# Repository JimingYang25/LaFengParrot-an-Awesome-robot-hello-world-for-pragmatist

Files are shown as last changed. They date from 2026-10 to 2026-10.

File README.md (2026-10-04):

# LaFengParrot

LaFengParrot is a 3D-printable, Jetson-powered parrot table robot with a
MuJoCo model and a reinforcement-learning locomotion stack. The mechanical
design targets a Jetson Orin Nano Super 8 GB and commonly available parts.

This repository is an engineering starting point for developers and
researchers who want to design, train, evaluate, and deploy their own robot
policies. It provides a reproducible mechanical and simulation baseline rather
than a finished consumer product.

## Current status
屏幕录制 2026-10-05 033540

- MuJoCo model: 10 actuators and a floating base; stable passive standing.
- Controller: PPO residual policy around an alternating six-joint leg reference.
- Verified checkpoint: `h008`, evaluated with 8% training-harness strength.
- Fixed-seed result: 19/20 episodes (`126..145`), zero cross-foot
  contacts, and about 0.54 m mean forward travel per 20 s.
- Graduation target: harness `0.00` and 20/20 strict evaluation episodes.
- Contact safety: floor contact and foot-to-foot collision are classified
  separately; any cross-foot contact fails evaluation.
- Current limitation: seed `141` exposes an early startup balance failure at
  `h008`, so the checkpoint is a development baseline, not a deployable gait.

exploded

The harness provides only lateral and attitude stabilization. It applies no
forward force, so forward travel must come from the robot's gait.

## Repository layout

| Path | Contents |
| --- | --- |
| `CAD/` | Parametric Python CAD sources, assembly notes, drawings, STL and STEP exports |
| `robot_description/` | MJCF, URDF, USD, meshes, kinematics and verification tools |
| `rl/` | Gymnasium environments, PPO training, evaluation and policy viewers |
| `BOM.md` | Bill of materials and component notes |

Policy developers should begin with the
[policy development and tuning guide](docs/POLICY_DEVELOPMENT.md). It explains
the observation/action contract, safe curriculum workflow, tuning controls,
evaluation gates, and how to connect another RL implementation.

## Verified development environment

- Windows with WSL2 Ubuntu 24.04
- Python 3.12 in a Conda environment
- MuJoCo 3.14.0
- Gymnasium 1.3.0
- Stable-Baselines3 2.9.0
- PyTorch 2.14.0 with CUDA 13.0

The saved policy uses a 60-value normalized observation, separate two-layer
`256 x 256` actor and critic networks, and a 10-value action vector. Only the
six leg residuals currently affect the walking command; wings and neck remain
at their reference positions.

## Clone the repository

```bash
git clone https://github.com/JimingYang25/LaFengParrot__An-Awesome-starting-point-for-your-policy.git LaFengParrot
cd LaFengParrot
```

All commands below are run from the repository root.

## Install Python dependencies

Python 3.12 is recommended. Create and activate an isolated environment, then
install the tested dependencies:

```bash
python -m pip install -r requirements.txt
```

For CUDA training, install the PyTorch wheel matching the host's CUDA setup
before running the command above. The CUDA-local build version may include a
suffix such as `+cu130`.

## Validate the robot model

From WSL2:

```bash
python robot_description/make_mjcf.py
python robot_description/verify_mjcf.py
```

## Watch the current policy

```bash
python rl/watch_gait_policy.py --harness 0.08
```

`--harness 0.00` is an experimental unassisted preview. The current checkpoint
has not yet passed the graduation test at that setting.

## Evaluate the checkpoint

```bash
python rl/evaluate_gait_ppo.py --episodes 20 --harness 0.08 --device cpu
```

The repository retains `rl/runs/gait_ppo_v3_valid/gait_ppo_final.zip` and its
`vecnormalize.pkl`. Intermediate checkpoints, TensorBoard logs, Python caches,
MuJoCo crash logs, and large generated SVG drawings are intentionally ignored.

## Next milestone

1. Improve startup robustness from 19/20 to 20/20 at harness `0.08`.
2. Gradually anneal the harness to zero without losing the collision gate.
3. Expand reset and push randomization, then repeat fixed-seed evaluation.
4. Validate actuator limits and add a hardware emergency-stop layer before
   transferring any learned policy to the physical robot.

## Collaboration and contact

Bug reports, reproducible experiments, and focused improvements are welcome
through GitHub issues and pull requests. For deeper collaboration involving
robot hardware, reinforcement learning, deployment, or research, contact
[2132720978@qq.com](mailto:2132720978@qq.com).

## License

Copyright 2026 Jiming ([JimingYang25](https://github.com/JimingYang25)).

This project—including its source code, robot descriptions, CAD files, and
documentation—is licensed under the [Apache License 2.0](LICENSE), unless a
file states otherwise.

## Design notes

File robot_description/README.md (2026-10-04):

# LaFengParrot — robot_description (REV-B)

Floating-base biped/quadriped-style parrot robot description for RL, generated **from the real
CadQuery CAD** (REV-B) into three mutually consistent formats:

| Format | File | Primary use |
|---|---|---|
| MJCF | `mjcf/lafengparrot.xml` | **PPO training asset (MuJoCo)** — primary |
| URDF | `urdf/lafengparrot.urdf` | PyBullet / ROS / general tooling |
| USD | `usd/lafengparrot.usd` | Isaac Sim / Isaac Lab (PhysX baked) |

All three are generated from **one frozen parameter source** (`kinematics.json`) + the real CAD
solids (meshes + inertials), so kinematic anchors, limits, inertials and contacts agree by
construction. A cross-format checker (`verify_cross.py`) re-asserts this on every run.

---

## 1. Kinematic tree (floating base, 10 actuated joints)

```
trunk (base_link, free joint — floating)
├── hip_roll_L (axis X)  ─ hip_pitch_L (Y) ─ knee_L (Y) ─ shin_L + foot
├── hip_roll_R (axis X)  ─ hip_pitch_R (Y) ─ knee_R (Y) ─ shin_R + foot
├── wing_flap_L (axis Y) ─ wing arm (fixed)
├── wing_flap_R (axis Y) ─ wing arm (fixed)
└── neck_yaw (axis Z) ─ neck_pitch (Y) ─ head
```

- **Servo mapping:** legs = Feetech **ST-3215-C018** (6×, effort 2.72 N·m); wings/neck = Feetech
  **SC-0043-C001** (4×, effort 0.22 N·m). All 10 on one FT-SCS bus in the real robot.
- **Zero pose = standing** (all joints at 0; soles level at global z = −138 mm).
- **Joint limits (deg; [EST] microduck-like):**

| joint | axis | origin (mm, trunk frame) | range |
|---|---|---|---|
| hip_roll L/R | X | (0, ±27, 0) | ±22° |
| hip_pitch L/R | Y | (0, ±27, −42) | ±90° |
| knee L/R | Y | (0, ±27, −84) | 0…150° |
| wing_flap L/R | Y | (0, ±62, 60) | ±45° |
| neck_yaw | Z | (0, 0, 133) | ±90° |
| neck_pitch | Y | (0, 0, 185) | ±45° |

## 2. Joint indexing — READ BEFORE WRITING RL CODE

MuJoCo assigns **qpos/qvel order by tree DFS** (leg-major): `hip_roll_L, hip_pitch_L, knee_L,
hip_roll_R, hip_pitch_R, knee_R, wing_flap_L, wing_flap_R, neck_yaw, neck_pitch` — this is the
correct, stable model order and must NOT be "re-ordered" by restructuring the tree.

The **actuator (ctrl) order is canonical** (kinematics.json order) because actuators bind to
joints by name.

→ Use `joint_name_index_map.json` to map names ↔ indices. **Index observations/actions BY NAME,
never by hard-coded position.**

| index type | layout |
|---|---|
| qpos (17) | 0–2 freejoint trans, 3–6 freejoint quat, 7–16 hinges (DFS order) |
| qvel (16) | 0–5 freejoint (3 trans + 3 rot), 6–15 hinges (DFS order) |
| ctrl (10) | canonical: hip_roll_L, hip_roll_R, hip_pitch_L, hip_pitch_R, knee_L, knee_R, wing_flap_L, wing_flap_R, neck_yaw, neck_pitch |

## 3. How to load

**MJCF (MuJoCo, PPO asset):**
```python
import mujoco
model = mujoco.MjModel.from_xml_path("mjcf/lafengparrot.xml")
data = mujoco.MjData(model)   # nq=17, nv=16, nu=10
```
- Position actuators (joint-target interface, 50 Hz): `ctrl` **in radians**, `ctrlrange` radians.
- Contacts: only the ten fixed sole facets (five per foot) touch the floor; the 32 mm flat
  centres provide standing stability and the raised toe/heel facets permit rollover. These are
  not wheels; visual/hull geoms remain `contype=0`.
  ground friction 1.0; sole friction (0.9, 0.005, 0.0001).
- `imu_trunk` site on the trunk at (0, 0, 0.05).
- Init helper: to start standing with the physical CAD sole on the ground, set the free base z
  so the trunk sits ≈ +0.138 m (the model itself has trunk pos = 0).

**URDF:**
```python
from urdfpy import URDF
r = URDF.load("urdf/lafengparrot.urdf")
```
- PyBullet: `p.loadURDF(..., useFixedBase=False)` — trunk becomes the 6-DOF floating base
  (no world joint needed). **PyBullet could not be installed on this machine (Python 3.14 has
  no wheel; source build fails on missing Python.h) — loading was verified with urdfpy instead
  (11 links / 10 joints, zero-pose FK reproduces all link frame origins with 0 error).**
- ROS: a world→base_link floating joint is added by the loader.

**USD (Isaac):**
```python
from pxr import Usd
stage = Usd.Stage.Open("usd/lafengparrot.usd")
```
- Physics **is baked**: ArticulationRootAPI ×1, RigidBodyAPI ×11, MassAPI ×11 (incl. diagonal
  inertia + principal axes), PhysicsRevoluteJoint ×10, DriveAPI ×10 (kp=40, kv=4, maxForce =
  servo effort), CollisionAPI ×13 (11 hulls + 2 sole cubes), visual UsdGeomMesh ×11.
- metersPerUnit = 1, up = Z. Load directly into Isaac Sim/Lab; joints are resolved by name.
- Drive stiffness/damping is a single set (legs and wings/neck not differentiated) — split per
  joint if needed.

## 4. Meshes & inertials (from the real CAD)

- `meshes/visual/<link>.stl` — tessellated real CadQuery solids (linear deflection 0.4 mm),
  already in each link's frame, **millimeters** (consumers scale: MuJoCo mesh scale="0.001").
- `meshes/collision/<link>_col.stl` — convex hulls for the same bodies.
- MJCF sole contact: five thin box facets per foot follow the 40×44 mm CAD rocker profile;
  the flat centre underside is local z=−54 mm and both ends rise to z=−52 mm.
- `inertials.json` — per-link mass (g), CoM (mm, link frame), inertia (kg·m², about CoM, link axes);
  includes the 105 g fastener/bearing/cable lump [EST] distributed by mass fraction.

**Mass & CoM reconciliation (matches REV-B CAD):**
total **1483.8 g** (target ≈ 1.485 kg) · whole-robot CoM height above floor **162.57 mm**
(target 162.5 mm).

## 5. Verification summary (2026-09-27)

| Check | Result |
|---|---|
| MJCF loads in mujoco | nq=17, nv=16, nu=10; 10/10 ranges; 400-step neutral sim stable, zero warnings, ncon=16; physical sole underside z = −0.1380 |
| Rocker crouch sweep | 0/10/15/20/25/30° knee targets all stable for 8 s; continuous contact; maximum trunk tilt 7.4° |
| URDF parses | urdfpy 11 links / 10 joints; axes+limits 10/10; zero-pose FK error 0.00e+00 m (PyBullet unavailable on Py3.14 — stated) |
| USD opens via pxr | ArticulationRootAPI 1, rigid bodies 11, revolute joints 10, drives 10, collision 13; axes+limits 10/10 |
| Cross-format | `verify_cross.py`: content 10/10 per format; URDF order canonical; MJCF actuator order canonical (qpos DFS documented); USD 10 names present (hierarchy-embedded) → **ALL THREE CONSISTENT** |

## 6. Generation pipeline (re-runnable)

```
CAD (poses.py, registry, dims) + dimensions.json
        └─ generate_meshes.py   → meshes/visual/*.stl, meshes/collision/*_col.stl, inertials.json
kinematics.json (single source)
        ├─ make_mjcf.py  (+ verify_mjcf.py)   → mjcf/lafengparrot.xml
        ├─ make_urdf.py  (+ verify_urdf.py)   → urdf/lafengparrot.urdf
        └─ make_usd.py   (+ verify_usd.py)    → usd/lafengparrot.usd
verify_cross.py   → cross-format consistency
make_name_map.py  → joint_name_index_map.json (from the actual MuJoCo model)
```

## 7. [EST] / limitations (honest list)

- **PyBullet load test skipped**: no Python 3.14 wheel; source build fails (missing Python.h).
  URDF correctness rests on urdfpy parse + FK.
- **Joint damping 0.5, frictionloss 0.05, kp=40, kv=4, armature 0.01 (legs) / 0.002 (wings·neck):
  [EST]** — tunable for PPO.
- **105 g lump** (fasteners/bearings/cables) and its placement: [EST].
- USD drives: single kp/kv set for all 10 joints; split per joint if needed.
- Joint limits are microduck-like estimates; verify against the physical servos (ST-3215 300°/s,
  SC-0043 similar) on first assembly.
- REV-B inherited values are authoritative here: hip rail 54 mm (±27), neck pitch local z 52 /
  global 185, carrier board-top z=72, soles z = −138, 40×44 soles, CoM 162.5 mm.

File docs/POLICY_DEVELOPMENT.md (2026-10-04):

# Policy development and tuning

This guide is for developers who want to fine-tune the included PPO policy,
change the locomotion task, or connect a different reinforcement-learning
algorithm to LaFengParrot.

The repository is a starting point, not a graduated walking controller. The
included checkpoint is usable with a training harness strength of `0.08`, but
it has not passed the assisted 20/20 gate or the unassisted (`0.00`)
graduation gate. Foot-to-floor and foot-to-foot contacts are classified
separately and covered by regression tests.

## 1. Reproduce the baseline first

Install the dependencies from the repository root:

```bash
python -m pip install -r requirements.txt
```

Validate the generated MuJoCo model:

```bash
python robot_description/make_mjcf.py
python robot_description/verify_mjcf.py
```

Evaluate and view the shipped checkpoint at its verified harness level:

```bash
python -m unittest -v tests.test_gait_contacts
python rl/evaluate_gait_ppo.py --episodes 20 --harness 0.08 --device cpu
python rl/watch_gait_policy.py --harness 0.08 --device cpu
```

Expected baseline for seeds `126..145`: 19/20 episodes pass, no episode has a
cross-foot contact, and seed `141` ends in an early startup balance failure.
Do not begin tuning until the model verifier, contact tests, and this baseline
are reproducible.

## 2. Understand the policy contract

The gait task is implemented in
[`rl/lafengparrot_gait_env.py`](../rl/lafengparrot_gait_env.py). It is a
residual controller: a phase-driven reference trajectory supplies the nominal
leg targets, and the policy adds bounded corrections every 20 ms.

```text
joint target = reference trajectory + filtered policy action * residual scale
```

### Observation

The observation contains 60 normalized values:

- 41 standing-state values: base height and orientation, ten joint positions,
  sixteen velocities, and the previous ten filtered actions.
- Two gait-clock values: sine and cosine of phase.
- Four foot position values: X/Z for the left and right feet.
- Four foot velocity values: X/Z for the left and right feet.
- Two measured contact flags.
- Two contact-point slip speeds.
- Four gait-event one-hot values.
- One current harness-strength value.

Global X/Y position is intentionally excluded so the policy does not depend on
where the robot happens to be in the world.

### Action

The action space is a ten-value `Box(-1, 1)`. The current gait controller uses
policy corrections on six leg joints:

| Action | Joint | Maximum residual correction |
| ---: | --- | ---: |
| 0 | `hip_roll_L` | +/-8 degrees |
| 1 | `hip_roll_R` | +/-8 degrees |
| 2 | `hip_pitch_L` | +/-18 degrees |
| 3 | `hip_pitch_R` | +/-18 degrees |
| 4 | `knee_L` | +/-20 degrees |
| 5 | `knee_R` | +/-20 degrees |
| 6-9 | Wings and neck | Disabled for gait (`0` scale) |

Actions are low-pass filtered as `0.8 * previous + 0.2 * new`. Changing the
action order, observation order, or observation size makes the shipped model
and `vecnormalize.pkl` incompatible unless their weights/statistics are
migrated deliberately.

### Harness

The training harness applies lateral stabilization and corrective body torque.
It never applies forward force. `1.0` is maximum training assistance and `0.0`
is fully unassisted. Treat harness reduction as a curriculum, not a reward
setting to change abruptly.

## 3. Use the environment with another algorithm

`LaFengParrotGaitEnv` follows the Gymnasium API, so it can be connected to
another RL library or a custom control loop:

```python
import numpy as np

from rl.lafengparrot_gait_env import LaFengParrotGaitEnv

env = LaFengParrotGaitEnv(
    target_speed=0.025,
    harness_strength=0.50,
    reset_noise_scale=0.25,
)

obs, info = env.reset(seed=0)
for _ in range(1000):
    action = np.zeros(env.action_space.shape, dtype=np.float32)
    obs, reward, terminated, truncated, info = env.step(action)
    if terminated or truncated:
        break

env.close()
```

For learned policies, normalize observations and preserve the normalization
statistics alongside every checkpoint. During evaluation, freeze observation
statistics and disable reward normalization.

## 4. Fine-tune the shipped PPO baseline

Create an experiment branch before training because the trainer writes its
final model back to `rl/runs/gait_ppo_v3_valid/`:

```bash
git switch -c policy/my-experiment
```

First stabilize any reward or environment change without reducing assistance:

```bash
python rl/train_gait_ppo.py \
  --resume \
  --quiet \
  --steps 200000 \
  --envs 8 \
  --reset-noise-scale 0.25 \
  --learning-rate 0.00005 \
  --start-harness 0.08 \
  --end-harness 0.08 \
  --device cuda
```

Re-evaluate at `0.08`. Only after reaching 20/20 with zero cross-foot contacts
should assistance be reduced. Use a slow stage rather than a jump:

```bash
python rl/train_gait_ppo.py \
  --resume \
  --quiet \
  --steps 1200000 \
  --envs 16 \
  --start-harness 0.08 \
  --end-harness 0.07 \
  --decay-fraction 1.0 \
  --device cuda
```

Then run:

```bash
python rl/evaluate_gait_ppo.py --episodes 10 --harness 0.07 --device cpu
python rl/analyze_gait_policy.py --harness 0.07
python rl/analyze_gait_actions.py 0.07
```

If the pass rate regresses, restore the last passing checkpoint rather than
continuing from a degraded policy. Keep the model ZIP and its matching
`vecnormalize.pkl` together.

The non-resume path in `train_gait_ppo.py` transfers weights and normalization
from `rl/runs/stand_ppo_rocker32/`. Those older standing artifacts are not
included in this repository. Public users should therefore fine-tune the
included gait checkpoint with `--resume`, or replace the standing-transfer
calls with an explicit initialization strategy in their own trainer.

## 5. Main tuning controls

Change one group at a time and record the commit, seed, harness schedule, and
evaluation results.

| Control | Location | Effect and risk |
| --- | --- | --- |
| Target speed | `--speed` | Changes the commanded forward-speed target. Increase gradually. |
| Harness schedule | `--start-harness`, `--end-harness`, `--decay-fraction` | Controls curriculum difficulty. Large jumps commonly destroy a passing gait. |
| Reference motion | `REFERENCE_KNOTS` | Changes lift, swing, touchdown, and double-support timing. Verify contact order after editing. |
| Gait frequency | `gait_frequency` | Changes cadence. Faster is not automatically more stable or faster forward. |
| Leg authority | `residual_scale` | Larger values permit recovery but also increase saturation and violent motion. |
| Initial-state difficulty | `--reset-noise-scale` | Improves robustness when raised gradually. |
| Resume learning rate | `--learning-rate` | Lower values reduce policy drift during narrow robustness refinements. |
| Reward terms | `step()` reward expression | Can change the learned behavior completely; validate physical metrics, not reward alone. |
| PPO optimization | `PPO(...)` in `train_gait_ppo.py` | Tune learning rate, rollout length, batch size, entropy, and network size conservatively. |

Monitor PPO training with:

```bash
tensorboard --logdir rl/runs/gait_ppo_v3_valid/tensorboard --port 6006
```

MuJoCo simulation remains primarily CPU-bound. CUDA accelerates the neural
network updates, while parallel environments increase simulation throughput.
More environments are useful only while the CPU can keep them supplied.

## 6. Evaluate physical behavior, not only reward

The provided evaluator marks an episode as passed only when:

- It does not terminate early.
- It completes at least four gait cycles.
- Every completed cycle is classified as a successful forward cycle.
- Trunk displacement is at least 0.08 m.
- No left/right sole collision occurs, even momentarily.

The gait audit additionally requires:

- Mean same-foot footprint advance above 5 mm.
- Worst integrated contact skid no greater than 8 mm.
- Every recorded touchdown lead above 3 mm.

A candidate graduates only after 20/20 deterministic episodes at harness
`0.00`, followed by visual inspection and action-saturation review. A policy
that stands on one leg, marches in place, slides its feet, or depends on the
harness has not graduated.

## 7. Contact-safety implementation

`_contacts_now()` reports a stance contact only for a sole-versus-floor pair.
Left/right sole contacts are counted independently, penalized immediately,
and terminate an episode when they persist for three control steps. The
evaluator is stricter: even one cross-foot contact makes the episode fail. A
lateral-separation term discourages leg crossing before collision.

The regression tests include a captured crossed-foot configuration lifted
above the floor. This verifies that self-collision is detected without being
misreported as ground contact or contact slip:

```bash
python -m unittest -v tests.test_gait_contacts
```

Keep physical collision enabled. The real robot cannot pass one foot through
the other, and disabling collision would invalidate the gait result.

## 8. Contribution workflow

Keep each change focused and make its result reproducible:

```bash
git switch -c policy/short-description
git add <changed-files>
git commit -m "Describe the policy change"
git push -u origin policy/short-description
gh pr create --base main
```

Include the training seed, steps, harness schedule, pass rate, mean distance,
gait-audit output, and a short video when opening a pull request. For deeper
hardware, RL, deployment, or research collaboration, contact
[2132720978@qq.com](mailto:2132720978@qq.com).

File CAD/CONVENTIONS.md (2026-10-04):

# LaFengParrot CAD — Conventions & Interfaces (FROZEN 2026-09-27)

This file is the contract every CAD module builds against. Do not deviate silently; if a convention is wrong, change this file and notify the other agents.

## 1. Paths (all Windows, absolute)

* CAD root: the repository-relative `CAD/` directory

* `dims\dimensions.json` + `dims\dimensions.md` — the ONLY source of truth for hardware dimensions (produced by the dimension-research agent; every number has `verified: true/false` and a `source` URL).

* `source\lib\` — hardware solid builders (servos, carrier, battery, power, fasteners, bearings). Pure functions: no frame/trunk design here.

* `source\frame\` — robot structural parts (trunk, legs, wings, neck, head, mounts, panels).

* `source\assembly\` — poses, full-assembly build, clash checks, drawings/export scripts.

* `exports\step\`, `exports\stl\`, `drawings\` — outputs.

* `ASSEMBLY.md` — part tree ↔ BOM mapping, dimension table, fastener list, cable routing, joint axes/zero poses.

## 2. Units & coordinate frame

* Units: **millimeters** everywhere. Mass in grams (metadata only).

* Global frame (right-handed): **+X forward** (parrot faces +X), **+Y left** (parrot's left), **+Z up**.

* Origin `(0,0,0)`: point on the sagittal plane midway between the two **hip\_roll output axes**, at the height of those axes (this is the "hip plane"). Legs hang below (−Z), trunk above (+Z), neck above trunk.

* Every part module builds in **its own local frame** (sensible local origin, documented in META\["origin\_note"]); the assembly module applies poses to place it.

## 3. Module API (every part file)

Each builder file in `source\lib\` and `source\frame\` exposes exactly:

```
META = {

&#x20; "part\_id": "trunk\_shell",            # unique, snake\_case, matches STL/STEP filenames

&#x20; "name": "Trunk shell (PETG)",

&#x20; "bom\_line": "§2 #9 / §6 #15",        # maps to BOM line(s); "n/a" for hardware

&#x20; "qty": 1,

&#x20; "mass\_g": 230.0,                     # datasheet/estimate

&#x20; "material": "PETG | aluminum | PCB | LiPo | steel",

&#x20; "source\_url": "...",                 # datasheet/listing; "n/a" for designed parts

&#x20; "origin\_note": "local frame: ...",

&#x20; "print\_note": "orientation, supports, split hint (if printed)",

}

def build(cfg=None):

&#x20;   """Return a cq.Solid (or cq.Workplane, callers normalize) of the part

&#x20;   in its local frame. cfg: optional dict for parametric overrides."""

&#x20;   ...
```

Registry: `source\registry.py` provides `all_parts() -> dict[part_id, module]` by importing every module in lib + frame and collecting `META` + `build`. Assembly iterates the registry.

## 4. Hardware dimensions — read ONLY from `dims\dimensions.json`

Frame parts that mount hardware (servo pockets, carrier standoffs, battery tray, hole patterns) MUST take their numbers from `dimensions.json`, never hardcode a dimension that exists in the JSON. The JSON schema (keys per part):

```
{

&#x20; "st3215\_c018": {

&#x20;    "body": {"l": 45.2, "w": 24.7, "h": 35.0},

&#x20;    "mount": {"holes": \[\[x1,y1],\[x2,y2],...], "diameter": 2.2, "screw": "M2"},

&#x20;    "shaft": {"spline": "25T", "outer\_d": 6.0, "length": 6.0, "axis\_dir": "body\_long"},

&#x20;    "horn": {"span": 40.0, "arm\_count": 4, "screw\_holes": "M2"},

&#x20;    "connector": {"type": "JST-PH 3pin", "location": "face\_opposite\_shaft"},

&#x20;    "mass\_g": 55.0,

&#x20;    "source": "\<url>", "verified": true

&#x20; },

&#x20; "sc0043\_c001": {...},

&#x20; "orin\_carrier": {"envelope": \[103,90.5,34.8], "board": \[100,79,1.6],

&#x20;    "mount\_holes": \[\[x,y],...], "mount\_screw": "M2.5",

&#x20;    "connectors": {"barrel": \[x,y], "40pin": \[x,y], "csi1": \[x,y], "csi2": \[x,y],

&#x20;                   "microsd": \[x,y], "usb": \[x,y], "fan\_exhaust": \[x,y]},

&#x20;    "module\_center": \[x,y], "source": "\<url>", "verified": false},

&#x20; "lipo\_3s\_2200": {"size": \[l,w,h], "mass\_g": 185, "connector": "XT60", "balance": "JST-XH", ...},

&#x20; "bec\_5v3a": {...}, "xt60\_switch": {...}, "fuse\_holder": {...},

&#x20; "imuc\_icm42688p": {...}, "bearing\_mr63": {"d":3,"D":6,"B":2.5}, "bearing\_mr84": {"d":4,"D":8,"B":2},

&#x20; "fastener\_m2": {"head\_d":3.8,"head\_h":2.0,"thread":2.0,"clear":2.2},

&#x20; "fastener\_m25": {"head\_d":4.5,"head\_h":2.5,"thread":2.5,"clear":2.7},

&#x20; "fastener\_m3": {"head\_d":5.5,"head\_h":3.0,"thread":3.0,"clear":3.2}

}
```

If a number is missing from the JSON, the frame part uses `[EST]` value from `dimensions.md` and marks it in `META["origin_note"]`. Never invent silently.

## 5. Clearances & print rules (PETG FDM)

* Moving-pair radial fit: shaft-in-bearing / servo-horn-on-shaft → nominal + **0.1–0.2 mm** on the bore, printed in PETG.

* Non-moving press/slip: screw boss bore = thread + 0.1 (self-tap) or clearance per §4 fastener table.

* Face-to-face mating clearance: **0.3–0.5 mm** on mating bosses/tabs.

* Wall thickness: structural walls **≥ 2.0 mm**, servo pockets **≥ 1.6 mm**, cosmetic shell **1.6 mm**.

* Screw bosses: OD = head\_d + 2× wall (min 6.0 mm for M2/M2.5, 6.8 for M3 at 2 mm wall), boss height ≥ 2× screw engagement.

* Print splits: the trunk shell is split (long axis or clamshell) so each printed piece fits ≤ 220×220 mm bed — mark `print_note` with the split; final split decision waits for the user's printer bed (flag, don't block).

* Corner radii ≥ 1 mm on printed parts (avoid stress risers); print orientation note in `print_note` (surfaces that must be dimensionally clean face away from supports).

## 6. Kinematic anchors & joint axes (MUST match the final ASSEMBLY.md and later MuJoCo model)

* **Legs (3 DOF/leg, mirroring microduck scaled to parrot):**

  * hip\_roll: axis ∥ **X** (frontal-plane abduction). Left/right hip\_roll axes separated **54 mm (±27 mm from sagittal, realized)**. Servo: ST-3215-C018, output shaft along X.

  * **CHANGE RECORD (2026-09-27, assembly clash check):** hip half-spacing widened from 34 mm to 52 mm total (planned) and realized at **54 mm (±27)** after the REV-B rebuild. Root cause: the ST-3215-C018 body (45.2×24.7×35, 55 g) makes the hip\_mount housing 50.6 mm wide in Y and the thigh link 38.4 mm wide; at ±17 mm the L/R housings, thigh beams and hip\_roll servo bodies overlap across the sagittal plane (measured 0.6–9.6 cm³ intersections). 54 mm total gives ≥1.5 mm per-side clearance on the widest part. Torque: hip\_roll lever arm r ≈ **33 mm** (half-spacing 27 + 6 mm roll margin) → required @2× = 0.961 N·m at M=1.485 kg vs C018 stall ≈ 2.72 N·m @11.1 V → **PASS with 2.83× margin** (still \~3.0× at the 1.38 kg frame+hardware mass). **MuJoCo kinematics must use 54 mm spacing** (recorded in ASSEMBLY.md).

  * hip\_pitch: axis ∥ **Y** (sagittal swing), located **42 mm** below the hip\_roll axis (thigh length between hip\_pitch output and knee axis).

  * knee\_pitch: axis ∥ **Y**, located **42 mm** below hip\_pitch (thigh link), shin runs **50 mm** from knee axis to ankle/foot (shin link).

  * Foot: small ground-contact pad at shin end, \~10 mm above floor in zero pose; keep CoM low (battery lowest, carrier above).

* **Wings (2 DOF):** one flap DOF each. Axis ∥ **Y** (wings spread sideways ±) — wing servo (SC-0043) mounted at the shoulders, output axis lateral, wing arm extending in the ±Y direction with a printed airfoil-ish flat panel.

* **Neck (2 DOF):** neck\_yaw axis ∥ **Z**, then neck\_pitch axis ∥ **Y**, both stacked above the trunk top, lifting the head \~60–80 mm above the trunk; head shell on top with beak + crest.

* **Zero pose (standing):** trunk vertical; all leg joint angles = 0 (legs straight down); wings level (±Y); neck straight up (yaw=0, pitch=0). The crouched gait (hip\_pitch 26°/knee \~0°) is a *policy* offset, not the CAD zero — record both in ASSEMBLY.md so MuJoCo inherits exact axes.

* **REV B — STABILITY REVISION (2026-09-27, user-directed):**

  * **Foot (in shin\_link, 2026-09-28 rocker update):** fixed compound-rocker sole **40 (X, heel→toe) × 44 (Y, lateral) × 4 mm maximum**, centered on the shin axis. The centre 32 mm is flat at local z = −54; two 2 mm facets per end rise through −53.4 to −52 at heel and toe. It is one printed solid with the shin—**not a wheel and not an extra assembly**. Leg drop remains 138 mm. Lateral inner gap between L/R soles = 10 mm (inner edges at y=±5 with track ±27).

  * **Neck:** neck\_linkage pitch axis lowered **z=70 → z=52** (H\_n = 52 mm, −26%): base+yaw block unchanged (0–25.4), yoke shortened; both SC-0043 servos keep full travel. Head crest falls accordingly (global pitch axis 203 → **185**). Head-pitched-down travel check: head shell front must clear the trunk roof (≥3 mm) at −45° pitch.

  * **Carrier mount (low CoG):** carrier board-top **z=101 → z=72** (realized; feet bottom ≈ 65.4, standoffs ≈ **33 mm \[EST]** from the trunk floor 33; cooler exhaust ≈ 100 with the roof vent at \~131.5 → \~28 mm plenum above; airflow is plenum-style, not direct). Battery tray seated on the trunk floor (base at z=33), battery stays y=−23 low.

  * **Cable stubs:** both servo modules' cosmetic 150 mm cable cylinders shortened to **15 mm** exit stubs (envelope becomes structural: x\[−56,+70], y\[−189,+189], z\[−138,\~250]).

  * **CoM target:** whole-robot CoM height ≤ \~180 mm using real frame mass (456 g PETG at 1.27) + hardware masses (\~1.36 kg total); support-polygon lateral half-base 49 mm (stance outer edge), forward half-base 20 mm; tipping angle = atan(half-base/CoM\_z). These revised dims are what the later MuJoCo model must inherit.

## 7. Assembly & outputs

* `source\assembly\poses.py`: one `def poses() -> dict[part_id, cq.Location]` for the standing pose and `def exploded() -> dict[part_id, cq.Location]` (offsets along ±X/±Y/±Z, ≥ 30 mm apart per direction).

* Full assembly STEP: `exports\step\LaFengParrot_full.STEP`; per-part STEP + STL also exported (STL in local frame, `print_note` gives print orientation — do NOT rotate STLs).

* Drawings (deterministic, from CAD data — NO AI image generation): front (XY), side (YZ) orthographic with key dimensions; exploded isometric. PNG + SVG (+ PDF if convenient). Use matplotlib-based projection of the part solids (or OCP offscreen if working).

* Clash check: pairwise solid intersection volume (OCP `BRepAlgoAPI_Common`) over the standing pose, report any pair with volume > 0.01 mm³; also confirm service access (microSD slot, XT60, barrel jack, 40-pin) is not fully enclosed.

## 8. Reporting

Every agent returns: absolute paths of outputs, the dimension table it used (with verified/EST + URL), fit/clash results, and any dimension it could NOT verify (explicitly marked). Nothing fabricated; unverifiable → \[EST] + flagged.

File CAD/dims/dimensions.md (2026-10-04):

# LaFengParrot CAD — Hardware Mechanical Dimensions

Build variant: **all-Feetech** — legs 6× ST-3215-C018 (12 V, 30 kg·cm), wings/neck 4× SC-0043-C001.
Units: mm (mass g). Research date 2026-09-27.

**Legend:** ✅ verified = read from a datasheet / product page this session. ⚠ [EST] = estimated; see the register at the end for the basis.

---

## 1. Feetech ST-3215-C018 (leg servos, ×6)

Source: official datasheet PDF https://www.feetech.cn/Data/feetechrc/upload/file/20240507/6385067068652648096680943.pdf ; outline drawing https://www.feetechrc.com/en/525603.html

| Dimension | Value (mm) | Verified? | Source | Notes |
|---|---|---|---|---|
| Body L × W × H | 45.2 × 24.7 × 35.0 | ✅ | datasheet §6-1 | "45.2X24.7X35" |
| Mount holes (output face) | 4× at (6.5,2.5)/(27.2,2.5)/(6.5,22.2)/(27.2,22.2) | ⚠ [EST] | measured off drawing Fig.9 | drawing does not label hole coords; pocket dim = body box |
| Mount hole Ø / screw | Ø2.2 / M2 (PA2.0 self-tap) | ⚠ [EST] | drawing "B-PA2.0自攻螺丝" | 4 corner PA2.0 case screws at ~(1.7,1.1)/(43.5,1.1)/(1.7,23.6)/(43.5,23.6) are case fasteners |
| Output shaft spline | 25T | ✅ | datasheet §6-9 | "25T/OD5.9mm" |
| Output shaft O/D | 5.9 | ✅ | datasheet §6-9 | |
| Output shaft length | ~6.0 | ⚠ [EST] | horn section X-X | dual-shaft (双轴); rear plain bore ~Ø6 opposite face |
| Axis direction | normal to 45.2×24.7 face | ✅ | drawing | |
| Horn: flange O/D | 19.95 (~20) | ✅ | horn drawing | octagonal flange |
| Horn: hub bore | 25T / Ø5.9 | ✅ | horn drawing "25T(5.9铜齿)" | |
| Horn: arm / bracket screws | 4× M3 (on ~Ø14 BCD) + 4× Ø3.2 clearance (~Ø9 BCD) | ✅ | horn drawing "4-M3" / "Ø3.2" | |
| Horn retaining screw | M3×6 | ✅ | datasheet §6-13 "M3X6机牙螺丝" | |
| Horn thickness | flange 2.5 / hub 4.5 | ✅ | horn section X-X | |
| Connector | 5264-3P, 2.54 pitch, 3-pin (GND/Vcc/SIG), 15 cm cable | ✅ | datasheet §6-7 | on bottom face opposite shaft |
| Mass | 55 g (±1) | ✅ | datasheet §6-8 | |

---

## 2. Feetech SC-0043-C001 (wings/neck servos, ×4)

Source: product page https://www.feetech.cn/en/559569

| Dimension | Value (mm) | Verified? | Source | Notes |
|---|---|---|---|---|
| Body L × W × H | 20.3 × 8.5 × 19.39 | ✅ | product page "A:20.3 B:8.5 C:19.39" | |
| Mount holes | 2 ears, Ø~2.0, center spacing 20.3 | ⚠ [EST] | outline drawing | bottom view dims 27.35 outer / 23.6 body / 20.3 hole spacing |
| Mount screw | M2 | ⚠ [EST] | drawing "Φ2" ear holes | |
| Output shaft spline | 28T | ✅ | product page "28T/Φ3.9mm" | |
| Output shaft O/D | 3.9 | ✅ | product page | |
| Output shaft protrusion | 3.1 | ✅ | side view "3.1" | |
| Horn retaining screw | M1.7 | ✅ | drawing "28T-M1.7" | |
| Stock horn arm span | ~15 | ⚠ [EST] | typical 4.3 g servo horn | |
| Connector | 3-pin bus, 15 cm cable | ✅ | product page "Connector wire: 15cm" | exact JST family not published |
| Mass | 6.6 g (±0.5) | ✅ | product page | |

---

## 3. Jetson Orin Nano Super dev-kit reference carrier + stock cooler

Source: NVIDIA Carrier Board Spec SP-11324-001 https://developer.nvidia.com/downloads/assets/embedded/secure/jetson/orin_nano/docs/jetson_orin_nano_devkit_carrier_board_specification_sp.pdf (Fig 4-1, Fig 4-2)

Coordinate system: origin = top-left of the 100×79 PCB, +X right, +Y down (mm).

| Dimension | Value | Verified? | Source | Notes |
|---|---|---|---|---|
| Overall envelope (w/ cooler+feet) | 103.0 × 90.5 × 34.77 mm | ✅ | Fig 4-2 | 103±0.2 / 90.5±0.2 / 34.77±1.09 |
| PCB size | 100.0 × 79.0 mm | ✅ | Fig 4-1 | 100±0.13 / 79±0.13 |
| PCB thickness | 1.57 mm | ✅ | Fig 4-1 side view | 1.57±0.16 |
| Component height (top side) | 16.70 mm max | ✅ | Fig 4-1 side view | |
| Component height (bottom) | 4.30 mm max | ✅ | Fig 4-1 side view | |
| Mount holes | (4,4)/(96,4)/(4,56)/(96,56) | ⚠ [EST] | measured off Fig 4-1 raster | spec gives no coords; 4 corner plated holes |
| Mount screw | M2.5 | ⚠ [EST] | standard dev-kit standoff | |
| Feet / standoff height | ~5 mm | ⚠ [EST] | BOM §2 CAD note | |
| Connector: DC barrel (J16) | (10, 66) | ⚠ [EST] | Fig 4-1 | barrel 5.5 O/D, 2.5 pin, 9.5 mm long (verified §3.8) |
| Connector: 40-pin header (J12) | (35, 5) | ⚠ [EST] | Fig 4-1 | top edge |
| Connector: CSI #0 (J20) | (3, 21) | ⚠ [EST] | Fig 4-1 | left edge, upper flex connector |
| Connector: CSI #1 (J21) | (3, 40) | ⚠ [EST] | Fig 4-1 | left edge, lower flex connector |
| Connector: microSD slot | (68, 62) | ⚠ [EST] | Fig 4-1 | bottom edge |
| Connector: USB cluster (USB-C J5) | (25, 68) | ⚠ [EST] | Fig 4-1 | USB-A J6/J7 at ~(42,68)/(55,68) |
| Fan exhaust (blows upward off heatsink) | (50, 30) | ⚠ [EST] | Fig 4-2 fan center | |
| SoDIMM module center | (48, 28) | ⚠ [EST] | Fig 4-1 | module sits above long SoDIMM slot |
| Dev-kit assembly mass | 175 g | ✅ | §4 "Developer Kit Weighs 0.175kg" | |

---

## 4. 3S 11.1 V 2200 mAh LiPo (XT60)

Source: Zeee listing https://zeeebattery.com/products/zeee-3s-lipo-battery-2200mah-11-1v-120c-xt60 (cross-checked Gens Ace / HRB / Rhino)

| Dimension | Value | Verified? | Source | Notes |
|---|---|---|---|---|
| Pack L × W × H | 105 × 34.5 × 26 mm | ✅ | Zeee listing | brands vary 105×33–35×19–27; Gens Ace 105×34×23, Rhino 107×35×26.5 |
| Mass | 185 g | ✅ | Zeee listing | |
| Discharge connector | XT60 | ✅ | listing | |
| Balance lead | JST-XH 4-pin | ✅ | listings | exits same end as XT60 |

---

## 5. 5 V / 3 A BEC module

| Dimension | Value | Verified? | Source | Notes |
|---|---|---|---|---|
| Board L × W × H | 30 × 20 × 10 mm | ⚠ [EST] | generic | small 2-side buck PCB; exact size varies by brand |
| Wire length | ~100 mm leads | ⚠ [EST] | generic | |
| Mass | 15 g | ⚠ [EST] | BOM §7 | |

---

## 6. XT60 power switch + inline fuse holder

| Dimension | Value | Verified? | Source | Notes |
|---|---|---|---|---|
| XT60 housing | 17.5 × 21.5 × 14 mm | ⚠ [EST] | standard XT60 part | |
| Inline switch body | 50 × 25 × 20 mm | ⚠ [EST] | generic | XT60 leads + rocker toggle |
| Glass fuse | Ø5 × 20 mm | ✅ | standard 5×20 | |
| Fuse holder body | 30 × 15 × 10 mm | ⚠ [EST] | generic inline holder | |

---

## 7. ICM-42688-P IMU breakout

Source: chip datasheet https://product.tdk.com/system/files/dam/doc/product/sensor/mortion-inertial/imu/data_sheet/ds-000347-icm-42688-p-v1.6.pdf

| Dimension | Value | Verified? | Source | Notes |
|---|---|---|---|---|
| Chip package | 2.5 × 3.0 × 0.91 mm LGA | ✅ | TDK datasheet | the bare IC |
| Breakout PCB | 20 × 20 × 2 mm | ⚠ [EST] | generic GY breakout | 4× M2 holes at corners (2,2)/(18,2)/(2,18)/(18,18), Ø2.2 |
| Mass | 4 g | ⚠ [EST] | BOM §2 | |

---

## 8. Bearings

| Bearing | d (bore) | D (outer) | B (width) | Verified? | Source |
|---|---|---|---|---|---|
| MR63ZZ | 3.0 | 6.0 | 2.5 | ✅ | https://detail.1688.com/offer/570803238776.html |
| MR84 (open) | 4.0 | 8.0 | 2.0 | ✅ | https://www.ktbearing.com/product/deep-groove-ball-bearing/deep-groove-ball-bearing-mr-series/ |

Note: shielded **MR84ZZ** is 4×8×**3** mm; the open MR84 used in the joint pockets is 4×8×2.

---

## 9. Fasteners (DIN 912 / ISO 4762 socket head cap screws)

Source: https://engineeringhardware.com/guide/standard/din-912-socket-head-cap-screws/

| Size | Head Ø dk | Head height k | Thread | Clearance hole | Lengths in BOM | Verified? |
|---|---|---|---|---|---|---|
| M2 | 3.8 | 2.0 | 2.0 | 2.2 | M2×6 | ✅ |
| M2.5 | 4.5 | 2.5 | 2.5 | 2.7 | M2.5×8 | ✅ |
| M3 | 5.5 | 3.0 | 3.0 | 3.2 | M3×10 | ✅ |

---

## Unverifiable / [EST] register

Every number below could NOT be read directly from a datasheet this session and is an estimate. Frame parts consuming these MUST mark them in `META["origin_note"]`.

| # | Item | Estimated value | Basis / method |
|---|---|---|---|
| 1 | ST-3215-C018 mount-hole xy coords | (6.5,2.5)/(27.2,2.5)/(6.5,22.2)/(27.2,22.2) | pixel-measured off the Fig.9 outline raster; drawing labels only body box (45.2×24.7) and shaft. Verify against physical servo. |
| 2 | ST-3215-C018 shaft protrusion length | ~6.0 mm | inferred from horn/hub section (hub 4.5 + spline engagement); not explicitly dimensioned. |
| 3 | SC-0043-C001 mount hole spacing | 20.3 mm | from bottom-view dimension "20.3" on the outline drawing; ear hole Ø~2 inferred (drawing labels Φ2 near shaft). |
| 4 | SC-0043-C001 horn arm span | ~15 mm | typical 4.3 g micro-servo horn; not on drawing. |
| 5 | SC-0043-C001 connector JST family | "3-pin" only | product page says 15 cm wire but not the connector part number. |
| 6 | Orin carrier mount-hole xy | (4,4)/(96,4)/(4,56)/(96,56) | pixel-measured off Fig 4-1 raster; NVIDIA spec gives board outline but no hole coordinates. |
| 7 | Orin carrier all connector xy (barrel/40pin/csi1/csi2/microsd/usb/fan/module center) | per table above | pixel-estimated off Fig 4-1/4-2 raster. |
| 8 | Orin carrier feet height | ~5 mm | BOM §2 packing note; not in SP-11324. |
| 9 | Orin carrier mount screw size | M2.5 | standard dev-kit standoff; not explicitly stated. |
| 10 | BEC 5V3A board size / wires / mass | 30×20×10 mm, 100 mm leads, 15 g | generic small buck module; BOM lists it as a generic item. |
| 11 | XT60 housing size | 17.5×21.5×14 mm | standard XT60 (not re-verified from a datasheet this session). |
| 12 | XT60 switch body size | 50×25×20 mm | generic inline switch listing. |
| 13 | Fuse holder body size | 30×15×10 mm | generic 5×20 inline holder. |
| 14 | ICM-42688-P breakout PCB size / holes | 20×20×2 mm, 4×M2 corners | generic GY breakout; only the bare chip (2.5×3×0.91) is datasheet-verified. |

No values were fabricated: every servo dimension the frame needs (body box, mount holes, shaft, horn) is present, every carrier connector coordinate is present (flagged [EST] where estimated), and every row carries either a verified source URL or an explicit [EST] basis.

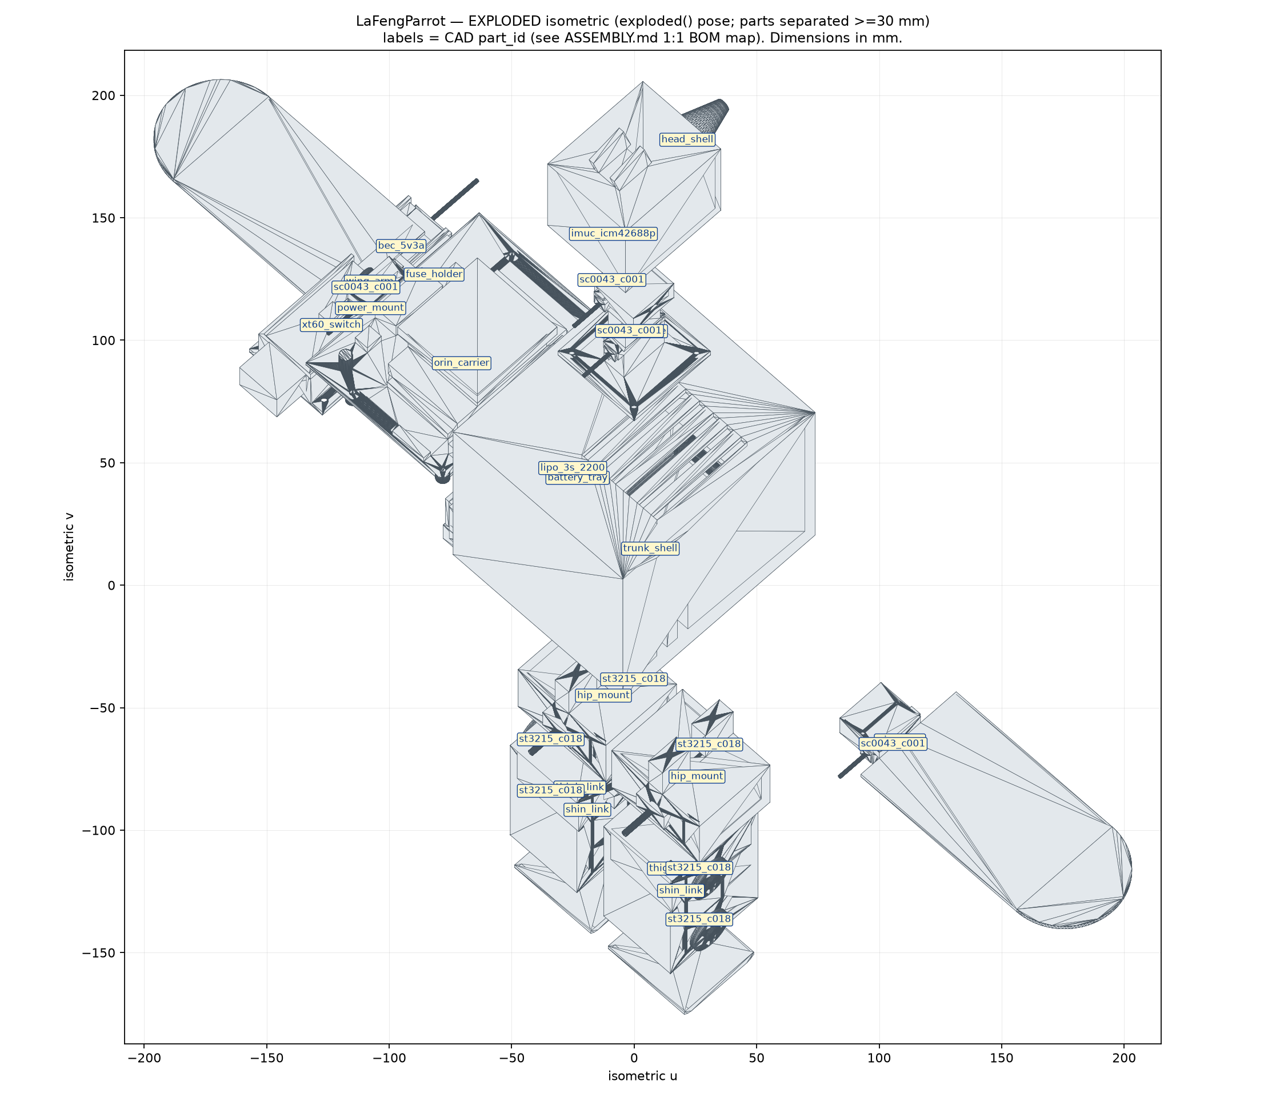
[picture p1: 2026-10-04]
CAD/drawings/exploded.png

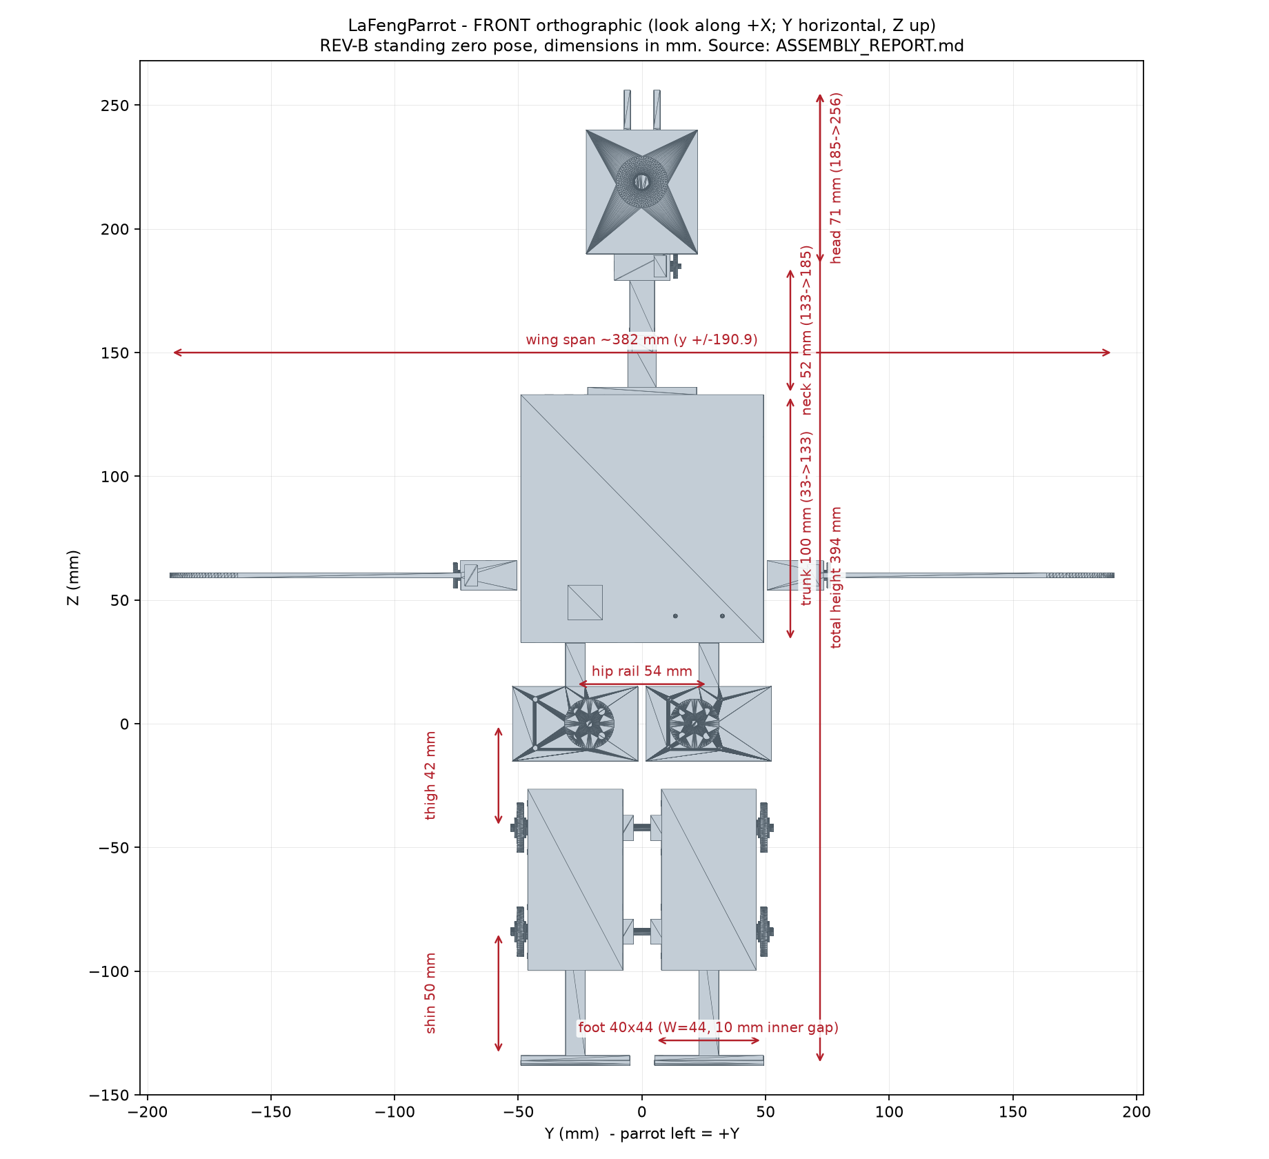
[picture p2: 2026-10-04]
CAD/drawings/front.png

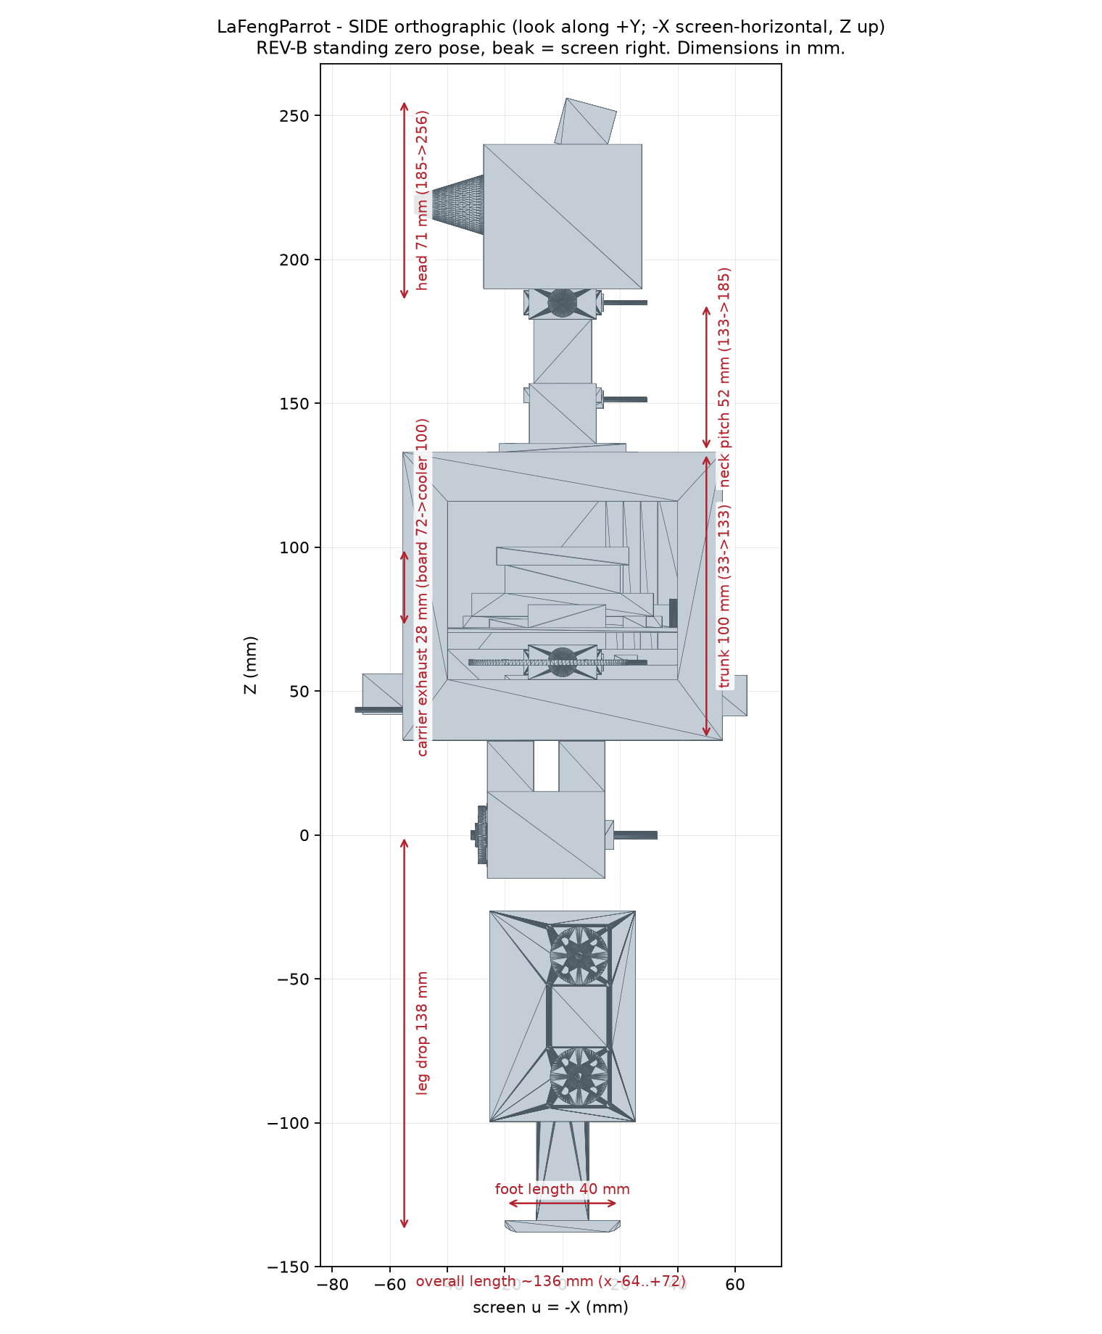
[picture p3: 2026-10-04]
CAD/drawings/side.png

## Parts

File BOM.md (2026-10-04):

# LaFengParrot — BOM & Engineering Baseline (Sep 2026, All-Domestic Edition)

**Project:** Parrot-shaped pet robot, ~25 cm class, analog of pollen-robotics/microduck.
**Compute (OWNED ✅, purchased 2026-09):** NVIDIA Jetson Orin Nano Super 8 GB **official developer kit** — module TW-T013-8GB mounted on the NVIDIA **reference carrier** with the **stock active cooler (heatsink+fan) pre-mounted**; JD [item 10149183026930](https://ic-item.jd.com/10149183026930.html). **The robot carries the reference carrier + stock cooler exactly as they ship** (cost ¥0, but their mass counts in §2); the A603 carrier / Waveshare cooler / NVMe are **NOT purchased**. Module: 69.6×45 mm, 260-pin SO-DIMM, 7/15/25 W, 67 INT8 TOPS.
**Behaviors (user-frozen v1):** bipedal WALK (microduck RL method), wing FLUTTER ×2, neck SHAKE/tilt. **NO flight.**
**Pricing snapshot:** 2026-09-27 (Sep 2026), CNY. **ALL materials purchasable inside mainland China** (Taobao/Tmall/JD/1688/domestic official flagship stores), domestic shipping only — no foreign-shipping options anywhere. Every value marked [ESTIMATE] is an inference, not a confirmed price; nothing was fabricated. FX ≈ 7.2 CNY/USD [ESTIMATE].

---

## 0. Scope — CORE vs OPTIONAL / DEFERRED

**CORE (v1, this BOM, 10 DOF, one servo bus):**
| Group | DOF | Servo |
|---|---|---|
| Legs ×2 — hip_roll + hip_pitch + knee_pitch (3 DOF/leg, BDX/OpenDuck-style) | 6 | Dynamixel XC330-M288-T |
| Wings ×2 — single flap DOF each (doubles as balance appendages during gait) | 2 | Dynamixel XL330-M288-T |
| Neck — yaw + pitch | 2 | Dynamixel XL330-M288-T |
| **Total core** | **10** | **6× XC330 + 4× XL330** |

**OPTIONAL (labeled, NOT core — v2+):**
- Legs → mirror microduck's *actual* 5 DOF/leg (add hip_yaw ±27°, ankle ±90°): **+4 servos ≈ +¥3,200, +46 g**. Microduck's real legs are 5 DOF (`hip_yaw, hip_roll, hip_pitch, knee, ankle` — 10 of its 15 servos); the extra yaw/ankle refine the waddle but the RL method (PPO in MuJoCo Warp, 50 Hz ONNX) transfers either way. [RL-README]
- Head/crest roll (+1), beak articulation, tail, camera, speaker/TTS, ToF, gamepad (teleop).

**DEFERRED (out of core, per scope):** everything above not in CORE or OPTIONAL.

---

## 1. Research corrections vs the working assumptions (read first)

1. **Microduck legs are 5 DOF, not 3** — `hip_yaw / hip_roll / hip_pitch / knee / ankle` per side, 10 servos; plus 4 head/neck servos + 1 beak servo = 15. There are **no wing or tail servos in microduck**. The beak is deliberately excluded from the RL action vector and daemon-driven. Its real geometry (from the shipping MuJoCo MJCF): trunk at z=0.12 m standing, hip half-spacing ≈34 mm, thigh ≈42 mm, shin ≈50 mm, crouch pose = hip_pitch 26° / ankle 26° / knee ~0°, robot 250×140 mm, **780 g**. [MJCF][CONST][ROBOTD-DESIGN]
2. **XL330/XC330-M288-T share a hard 6.0 V absolute max** — there is no 7.4 V operation for these SKUs (the 9–12 V row in the eManual belongs to the XC330-T288, a different model). A 2S pack (8.4 V charged) overvolts them. Microduck *does* run XL330s straight off the 2S NP-F550 rail (6.5–8.2 V) and clears the overvoltage-shutdown bit (shutdown=52) — a proven-but-out-of-spec hack. **This build does not copy that**: servos run from a regulated 6.0 V rail. [ROBOTD-DESIGN][XL330][XC330]
3. **Dynamixel bus connector is 3-pin JST-EH** (Robot Cable-X3P), not 4-pin. X4P is RS-485 Dynamixels only. [XL330][CN-CHANNEL]
4. **No surveyed Orin carrier accepts 2S (7.4 V) directly** — every board's input regulator cuts out at 9 V minimum. The LiPo that fits all 9–20 V carriers is **3S 11.1 V (9.9–12.6 V)**. [CARRIER]
5. **The open sibling Open Duck Mini independently converged on XC330 legs** — repo README: *"I switched to using `xc330-M288-T` servomotors instead of `xl330-M288-T` for the legs. They are more expensive, but way more powerful."* This is external validation of the torque analysis in §3. [ODM]
6. **Domestic-channel price correction (Sep 2026):** the earlier "MicroDuck crunch ¥950–1800" figure was overstated. Verified domestic prices today: **XL330-M288-T ¥95 (智能佳机器人, authorized distributor, in stock, verified 2026-09-02) / ¥238 (WowRobo, 48 h ship, 100+ orders) / ¥120–188 (1688)**; **XC330-M288-T ≈ ¥800 (multiple Taobao "韩国原装正品" listings), ¥700–900 band**. ROBOTIS has no Tmall/JD flagship — its China office (china@robotis.com) directs buyers to Taobao, where its **first authorized partner since 2007, 智能佳机器人 (BJRobot, bjrobot.jd.com / rosrobot.cn)**, sells genuine units. The 20 g + ≥0.9 N·m + Dynamixel-bus niche has **no domestic equivalent** as of Sep 2026 (Feetech STS3215 = 3× heavier + incompatible protocol; Unitree S288 = private 1-Wire protocol; Feetech SC09 = 0.23 N·m, insufficient) — so the proven servo selection stands and is buyable domestically. [CN-CHANNEL][CN-BACKUP]

---

## 2. Mass build-up (bottom-up)

Target: **≤ 1.15 kg** (microduck is 780 g; Orin compute stack replaces RK3566/Radxa Zero 3W). Worst-case design point for the torque budget: **1.20 kg**.

| # | Item | Qty | Unit mass (g) | Subtotal (g) | Status |
|---|---|---|---|---|---|
| 1 | Jetson Orin Nano Super module (bare) | 1 | 15 | 15 | [ESTIMATE 13–30 g, not published; SO-DIMM-class] |
| 2 | Reference carrier + stock active cooler + feet (dev-kit board assembly, owned) | 1 | 160 | 160 | [derived: verified dev-kit board assembly 0.175 kg (NVIDIA Carrier Spec SP-11324-001, "The Developer Kit Weighs 0.175kg") − module 15 g = 160 g; ESTIMATE split: carrier ~100 g / cooler ~50–55 g / feet ~10–15 g] |
| 3 | XC330-M288-T (legs) | 6 | 23 | 138 | datasheet |
| 4 | XL330-M288-T (wings + neck) | 4 | 18 | 72 | datasheet |
| 5 | JST-EH 3-pin bus cables | 12 | 2 | 24 | [ESTIMATE per cable] |
| 6 | Hobbywing UBEC 10 A (6 V rail) | 1 | 45 | 45 | [ESTIMATE] |
| 7 | 3S 11.1 V 2200 mAh LiPo (XT60) | 1 | 185 | 185 | listing |
| 8 | Fuse holder + 10 A fuse + XT60 switch | 1 set | 30 | 30 | [ESTIMATE] |
| 9 | PETG frame: trunk shell + leg links + head shell | — | 230 | 230 | [ESTIMATE; filament ~0.6 kg incl. ~15% supports/iterations → ~0.5 kg parts, split across legs/trunk/head; duck trunk core 264 g incl. electronics; trunk sized for the dev-kit stack — see CAD note] |
| 10 | Fasteners, servo idler horns, bearings (MR63/MR84) | — | 60 | 60 | [ESTIMATE] |
| 11 | ICM-42688-P body IMU breakout | 1 | 4 | 4 | [ESTIMATE] |
| 12 | Wiring, sleeving, bulk capacitor (2200 µF) | — | 45 | 45 | [ESTIMATE] |
| | **TOTAL (robot-mounted)** | | | **≈ 1008 g ≈ 1.01 kg** | |

Notes: 2 spare servos (1× XC330, 1× XL330) are purchased but not mounted. The balance charger (格氏 B3) and the USB→TTL bench adapter are bench equipment, not robot-mounted. If a second battery is carried for hot-swap, +185 g (→ 1.19 kg, still inside the 1.20 kg design point). The robot flies the **dev-kit board assembly as-is**: its verified 175 g (carrier + module + stock cooler + feet) is only ~4 g lighter than the A603 + Waveshare + NVMe stack it replaces (179 g), so total mass stays ≈ 1.01 kg.

**CAD / packaging note:** the trunk must fit the full dev-kit envelope **103 × 90.5 × 34.8 mm** (height explicitly includes feet, carrier board, module and thermal solution — verified [DEVKIT]). Plan trunk interior ≥ **105 × 92 mm footprint × ≥ 36 mm tall**, top **vented** so the stock cooler's fan (blows upward off the heatsink) gets airflow; mount on standoffs matching the carrier's ~5 mm feet so the bottom connectors (USB-A, DP, DC jack) clear the deck. This is the real tradeoff vs the A603 (87×52×26 mm): roughly 2× the footprint and 1.4× the height, so the printed trunk is a bit larger (+~10–20 g frame [ESTIMATE], at the margin of the 230 g line) — zero extra cost, already in hand.

**Variant — all-Feetech servo build (§7):** servo mass 356 g (+146 g vs the 210 g Dynamixel mix) → robot ≈ 1.15 kg (at the target ceiling; no second battery). Binding hip_roll @2× = 0.91 N·m vs ST-3215-C018 ≈ 2.72 N·m @11.1 V → **PASS 3.0×** (full details in §7).

---

## 3. Joint-torque budget

**Model (worst-case statics + dynamic margin):**
- Robot mass **M = 1.20 kg** (worst-case design; build estimate 1.01 kg) → weight **W = M·g = 11.77 N** (g = 9.81).
- **Single-leg support** worst case (the other leg mid-swing), body on one leg, crouched gait (hip_pitch 26° / knee ~0° mirroring microduck's HOME pose).
- Lever arms **r** (mirrored from microduck's published MJCF, scaled): hip_roll r = 40 mm (hip half-spacing 34 mm + body-roll margin), hip_pitch r = 25 mm (CoM sagittal offset during stride), knee_pitch r = 25 mm, optional ankle r = 15 mm.
- **Dynamic safety margin 2.0×** on the static value (covers weight transfer, lateral accel, ground reaction spikes; the RL gait is 50 Hz, not ballistic).
- Servo stall values (datasheet): XL330-M288-T **0.52 N·m @5 V / 0.60 N·m @6 V**; XC330-M288-T **0.93 N·m @5 V / 1.10 N·m @6 V**. Stall = transient peak; keep sustained load ≤ ~50% stall (the 2× margin does that).

| Joint | r (mm) | Static τ = W·r (N·m) | Required τ ×2 (N·m) | XL330 @6 V (0.60) | XC330 @5 V (0.93) | XC330 @6 V (1.10) | **Verdict** |
|---|---|---|---|---|---|---|---|
| hip_roll | 40 | 0.47 | **0.94** | FAIL (0.64×) | MARGINAL (0.99×) | **PASS (1.17×)** | ✅ XC330 @6 V |
| hip_pitch | 25 | 0.29 | **0.59** | MARGINAL (1.02×) | PASS | PASS | ✅ XC330 |
| knee_pitch | 25 | 0.29 | **0.59** | MARGINAL (1.02×) | PASS | PASS | ✅ XC330 |
| wing (flap) | 90 arm | ~0.02 | <0.15 | PASS | — | — | ✅ XL330 |
| neck (yaw/pitch, 140 g head @55 mm) | 55 | 0.08 | 0.15 | PASS | — | — | ✅ XL330 |

**Pass/fail conclusion:**
- **XL330 legs FAIL** for this robot: the binding joint (hip_roll, frontal-plane weight transfer) needs 0.94 N·m at the 1.2 kg design point vs 0.60 N·m available — a 1.6× shortfall. The duck itself only survives because it weighs 0.78 kg (hip_roll req 0.61 ≈ 0.60, effectively zero margin) **and** overvolts to 6.5–8.2 V.
- **XC330-M288-T legs PASS** with the 2× margin when run at **6.0 V** (1.10 N·m vs 0.94 required = 1.17× on the 2×-scaled load ≈ 2.3× vs the static base). At 5 V the same joints are marginal at 1.2 kg (0.93 vs 0.94), so **run the servo rail at 6.0 V**. At the **1.01 kg build** hip_roll needs only 0.79 N·m → PASS with **1.39×**; the PASS ceiling is **M = 1.40 kg** (1.10 / 0.785), so legs stay PASS for any build up to that mass.
- Wings and neck are light-load joints → **XL330** is correct there.

**Mass sensitivity — the binding hip_roll joint (required @2× = 0.785·M):**
| Robot mass | Required | XL330 @6 V | XC330 @5 V | XC330 @6 V |
|---|---|---|---|---|
| 0.78 kg (microduck) | 0.61 | FAIL (−2%, duck only works overvolted) | PASS | PASS |
| 1.01 kg (this build, dev-kit stack) | 0.79 | FAIL | PASS | PASS (1.39×) |
| 1.20 kg (worst, incl. hot-swap battery) | 0.94 | FAIL | MARGINAL | **PASS (1.17×)** |
| 1.40 kg (PASS ceiling) | 1.10 | FAIL | FAIL | MARGINAL (= stall, 0 margin) |

**Feetech-variant check (§7):** at M = 1.15 kg, hip_roll required @2× = 0.91 N·m; **ST-3215-C018 @11.1 V ≈ 2.72 N·m → PASS (3.0×)**; hip_pitch/knee 0.59 N·m → PASS; wings 0.15 N·m vs SC-0043 0.216 N·m → PASS (1.4×).

**Servo decision (single bus, single family):** legs **6× XC330-M288-T**, wings/neck **4× XL330-M288-T** → 210 g total servo mass, one Protocol-2.0 TTL daisy-chain, one 6 V rail (mixing is drop-in: same protocol, same 3-pin connector, same baud table — verified). [XC330][XL330]
**Domestic availability of this exact selection: CONFIRMED** — 智能佳机器人 (authorized) + Taobao resellers stock both SKUs today (see §Domestic sourcing guide); torque conclusion stands unchanged. [CN-CHANNEL]

---

## 4. Bus & control architecture (mirrors microduck's proven setup)

- One **half-duplex TTL bus @1 Mbps**, Dynamixel Protocol 2.0, all 10 servos daisy-chained (IDs unique), exactly like microduck's `/dev/ttyS2` @1 Mbaud (which carries 15 servos + the IMU board on one bus). Control loop: one `sync_read` (pos/vel/current) + one `sync_write` @50 Hz, matching microduck's loop. [ROBOTD-DESIGN]
- **On-robot interface:** reference-carrier 40-pin header **UART1** (pin 8 TX / pin 10 RX, 3.3 V) + **SN74LVC1G126** (single tri-state buffer, SOT-23-5, active-high enable) wired to the single DATA line; a free GPIO drives the buffer enable: HIGH = transmit (Orin drives the bus), LOW = receive (buffer hi-Z, servo drives). No level shifter needed (bus is 3.3 V, 5 V-tolerant). Orin UART synthesizes up to ~4.25 Mbps; 1 Mbps is the proven sweet spot for 10 joints. [XC330][CARRIER]
  - SN74LVC1G126 / SN74LVC126A / 74HC125 are stocked domestically on **LCSC 立创商城 (¥0.5–2/pc)** and Taobao. [CN-BACKUP]
- **Bench interface (domestic, replaces imported U2D2):** **Feetech URT-1** USB→485→TTL half-duplex adapter (Taobao 飞特官方, **¥30–60 [EST]**, auto direction-control — no GPIO toggling, supports 1 Mbps). It is electrically a generic half-duplex TTL transceiver; the Dynamixel protocol lives in the software driver, so it bridges an XL330/XC330 bus fine (verify direction wiring on the bench). Backup options: FASHION STAR UC-01 (¥20–40 [EST], auto-direction), or the genuine **ROBOTIS U2D2 sold domestically by 智能佳** (JD item 10152431689448, ¥250–350 [EST]) if you want Dynamixel Wizard 2.0 tooling. [CN-CHANNEL][CN-BACKUP]
- **Not used in the primary build:** Feetech STS3215 — different packet protocol (0xFF 0xFF / 8-bit checksum vs Dynamixel Protocol 2.0 / 16-bit CRC) and 3× heavier; it **cannot share the Dynamixel daisy-chain** (it needs its own UART + transceiver + Feetech SDK). If the all-Feetech architecture is adopted (§7), the Feetech bus becomes the single bus for all 10 servos. [STS][FTECH-BUILD]

---

## 5. Power architecture (voltages AND currents consistent)

Battery: **3S 11.1 V 2200 mAh LiPo, XT60** (9.9–12.6 V) — the only LiPo that fits every surveyed carrier's 9–20 V input; 2S (max 8.4 V) cannot boot any of them. [CARRIER][PERIPH]

```
3S 11.1 V 2200 mAh (XT60)
 ├─ 10 A inline fuse → XT60 switch
 │   ├─ reference carrier barrel (9–20 V):  Orin rail
 │   │    15 W walking mode ≈ 1.4 A avg @11.1 V (≤3 A board rating OK);
 │   │    25 W boost ≈ 2.3 A — bench only; set battery cutoff ≥ 9.6 V
 │   └─ Hobbywing UBEC 10 A → 6.0 V servo rail (setpoint 5.9–6.0 V, abs max 6.0 V)
 │        XL330/XC330-M288-T all ≤6.0 V cap — NEVER feed LiPo directly
 │        Realistic gait draw ≈ 3–6 A bursts; theoretical all-stall = 19.9 A
 │        (6×2.15 + 4×1.74) → UBEC 10 A cont / 15 A peak + 2200 µF low-ESR
 │        bulk cap at the first servo node; 15 A slow-blow fuse optional on rail
 └─ (optional) balance plug JST-XH → 格氏 B3 balance charger (CORE purchase, §6)
```

Bench: servo rail from **Mean Well LRS-50-5 (5 V/10 A)** — domestic via Taobao/1688 [EST ¥71–99]; carrier from its own 19 V PSU or the 3S pack. [SERVO][PERIPH]

Runtime: 3S 2200 mAh = 24.4 Wh; ~15–19 W average draw (Orin + 10 servos) → **~1.2–1.5 h** [ESTIMATE], vs microduck's ~1 h on NP-F550 (2S 2600 mAh ≈ 19 Wh, implied 19 W).

---

## 6. Recommended purchase list — ALL-DOMESTIC (CNY, Sep 2026)

All lines ship from inside mainland China. Prices: verified listing or [ESTIMATE] band as marked. Domestic-specific keywords and channels in the §"Domestic sourcing guide".

| # | Part | Qty | Unit ¥ | ¥ | Mass mounted (g) | Store link | Channel / note |
|---|---|---|---|---|---|---|---|---|
| 1 | NVIDIA reference carrier + stock active cooler + feet (dev-kit board assembly, owned) — replaces A603 | 1 | 0 (included) | 0 | 160 | [JD商品页·已购开发套件](https://ic-item.jd.com/10149183026930.html) | NOT PURCHASED — 随开发者套件附带; 103×90.5×34.8 mm; mass per §2 (verified 175 g assembly) |
| 2 | Waveshare Orin-FAN-PWM cooler — NOT purchased (stock NVIDIA cooler used, pre-mounted) | 0 | — | 0 | 0 | [微雪·官方商品页](https://www.waveshare.com/orin-fan-pwm.htm) | 链接仅作参考; 质量含于 §2 第 2 行 |
| 3 | WD SN740 2242 NVMe — DEFERRED (dev kit boots from microSD; ONNX policy is tiny; NVMe only speeds host data/training, not robot inference) | 0 | — | 0 | 0 | [JD搜索 SN740 2242](https://search.jd.com/Search?keyword=SN740%202242&enc=utf-8) | deferred, not core |
| 4 | Dynamixel XC330-M288-T (legs) | 6 | 800 | 4,800 | 138 | [淘宝搜索 XC330-M288-T 舵机](https://s.taobao.com/search?q=XC330-M288-T%20%E8%88%B5%E6%9C%BA) | 智能佳 / Taobao "韩国原装正品" [EST 700–900]; 确认 **-T (TTL)** 后缀 |
| 5 | Dynamixel XL330-M288-T (wings/neck) | 4 | 238 | 952 | 72 | [智能佳·淘宝商品页 ¥95](https://item.taobao.com/item.htm?id=638117456346) · [WowRobo·淘宝商品页 ¥238](https://item.taobao.com/item.htm?id=929725677792) | band ¥95–238; 智能佳库存间歇, WowRobo 48h发货 |
| 6 | Spares: XC330 ×1 + XL330 ×1 | 2 | — | 1,038 | 0 (spares) | [淘宝搜索 XC330](https://s.taobao.com/search?q=XC330-M288-T%20%E8%88%B5%E6%9C%BA) · [智能佳·XL330 商品页](https://item.taobao.com/item.htm?id=638117456346) | 同 4/5 渠道 |
| 7 | JST-EH 3-pin bus cables (Robot Cable-3P compatible), ~20 pc | 20 | 3 | 60 | 24 | [淘宝搜索 JST-EH 3P 舵机线](https://s.taobao.com/search?q=JST-EH%203P%20%E8%88%B5%E6%9C%BA%E7%BA%BF) | 智能佳 "Robot Cable-3P" 或通用 JST-EH 3P [EST 2–5/pc]; 确认3pin非4pin |
| 8 | SN74LVC1G126 ×5 (bus transceiver + spares) | 5 | 1 | 5 | ~0 | [立创商城搜索 SN74LVC1G126](https://www.szlcsc.com/search?q=SN74LVC1G126) | LCSC/淘宝 [¥0.5–2/pc] |
| 9 | Feetech URT-1 USB→TTL half-duplex adapter (bench) | 1 | 45 | 45 | 0 (bench) | [淘宝搜索 飞特 URT-1 调试板](https://s.taobao.com/search?q=%E9%A3%9E%E7%89%B9%20URT-1%20%E8%B0%83%E8%AF%95%E6%9D%BF) | 淘宝 飞特官方 [EST 30–60]; U2D2 国内备选见§4 |
| 10 | Hobbywing UBEC 10 A (6 V servo rail) | 1 | 80 | 80 | 45 | [淘宝搜索 好盈 UBEC 10A](https://s.taobao.com/search?q=%E5%A5%BD%E7%9B%88%20UBEC%2010A) | 好盈官方店/淘宝 [EST 40–80] |
| 11 | 3S 11.1 V 2200 mAh LiPo XT60 (+1 spare) | 2 | 80 | 160 | 185 | [淘宝搜索 3S 2200mAh 航模锂电池 XT60](https://s.taobao.com/search?q=3S%202200mAh%20%E8%88%AA%E6%A8%A1%E9%94%82%E7%94%B5%E6%B1%A0%20XT60) | 淘宝/1688 [EST 60–120] |
| 12 | **格氏 Gens Ace B3 balance charger (CORE)** | 1 | 105 | 105 | 0 (bench) | [淘宝搜索 格氏 B3 平衡充](https://s.taobao.com/search?q=%E6%A0%BC%E6%B0%8F%20B3%20%E5%B9%B3%E8%A1%A1%E5%85%85) | 格氏官方店/淘宝 [EST 80–130] |
| 13 | XT60 power switch + inline 10 A fuse + holder | 1 set | 20 | 20 | 30 | [淘宝搜索 XT60 开关 航模 保险丝座](https://s.taobao.com/search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) | 淘宝 [EST 10–25] |
| 14 | ICM-42688-P 6-axis SPI breakout (body IMU) | 1 | 60 | 60 | 4 | [淘宝搜索 ICM42688P 六轴IMU](https://s.taobao.com/search?q=ICM42688P%20%E5%85%AD%E8%BD%B4IMU) | 淘宝 GY模块 [EST 25–60] |
| 15 | MPU6050 breakout (optional head IMU) | 1 | 10 | 10 | 2 | [淘宝搜索 MPU6050 模块 GY-521](https://s.taobao.com/search?q=MPU6050%20%E6%A8%A1%E5%9D%97%20GY-521) | 淘宝 |
| 16 | PETG filament 1 kg (PolyMaker PolyLite / 金质) | 1 | 70 | 70 | 230 (printed) | [淘宝搜索 PolyLite PETG 1kg](https://s.taobao.com/search?q=PolyLite%20PETG%201kg) | PolyMaker官方店/淘宝 [EST 60–90] |
| 17 | M2/M2.5/M3 304 screw kit | 1 | 20 | 20 | — | [淘宝搜索 M2 M2.5 M3 螺丝套装 304](https://s.taobao.com/search?q=M2%20M2.5%20M3%20%E8%9E%BA%E4%B8%9D%E5%A5%97%E8%A3%85%20304) | 淘宝 [EST 15–35] |
| 18 | MR63/MR84 bearings (~25 pc) | 25 | 1 | 25 | — | [淘宝搜索 MR63ZZ MR84ZZ 微型轴承](https://s.taobao.com/search?q=MR63ZZ%20MR84ZZ%20%E5%BE%AE%E5%9E%8B%E8%BD%B4%E6%89%BF) | 淘宝 [EST 1–5/pc] |
| 19 | FPX330-H101 idler horn set (4 pc) — **1 set as reference; primary path = PETG 3D print** | 1 | 65 | 65 | — | [淘宝搜索 FPX330-H101 支架套装](https://s.taobao.com/search?q=FPX330-H101%20%E6%94%AF%E6%9E%B6%E5%A5%97%E8%A3%85) | 淘宝 [EST 50–80/set]; printed horns ~¥1 filament |
| 20 | PET braided sleeving 2 m | 2 | 2.5 | 5 | — | [1688搜索 编织网管 包线管](https://s.1688.com/selloffer/offer_search.htm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) | 1688/淘宝 |
| | **TOTAL (all-domestic)** | | | **≈ ¥7,523** | **≈ 1,008 g (per §2)** | — | |

**Link legend:** `官方商品页` = verified manufacturer/official product page (live-checked); `商品页·店名` = verified distributor item page (Taobao/JD item IDs from 2026-09-02 verified research — these block automated crawlers but open normally in a browser); `淘宝搜索/JD搜索/1688搜索/立创商城搜索` = pre-filled search URL for the exact Chinese keyword (also bot-walled, opens in browser).

Mounted robot mass ≈ 1.01 kg (§2) ✓ within target; servo cost = **¥6,790 ≈ 90% of the total** — the biggest cost driver. (Prior editions: ≈ ¥10,330 → all-domestic ≈ ¥9,290 → **≈ ¥7,523** after removing A603 ¥1,400, Waveshare cooler ¥67 and NVMe ¥300 — the compute stack is the owned dev-kit reference carrier + stock cooler at ¥0.)

---

## 7. Cheaper servo architecture (Dynamixel stays the premium option — fully costed labeled alternative)

1. **Enterprise/tiered pricing via the authorized distributor:** contact **智能佳机器人** (china@robotis.com / 400-099-1872 / rosrobot.cn) as a research buyer — they offer 企业会员 bulk invoicing and tiered pricing at 5-/10-unit quantities; the ¥95 XL330 price is their listed SKU (intermittent stock). For 12 servos this is the biggest legitimate saving on the premium path (~¥1,000+ vs walk-in resale). [CN-CHANNEL]
2. **All-Feetech single-bus build (the cheap option, verified 2026-09-27):** legs **6× ST-3215-C018 (12 V)** + wings/neck **4× SC-0043** — both speak the same Feetech **FT-SCS half-duplex TTL protocol**, so all 10 servos share **ONE bus and ONE SDK**. The C018 is rated **4.0–14 V** (OV trip >14 V) → legs run **directly from the 3S pack** (9.9–12.6 V), no leg buck; SC-0043 (3.7–6 V) needs a small 5 V BEC. Servo cost drops ¥6,790 → ≈ **¥1,205 (−82%)**; total BOM ≈ ¥7,523 → ≈ **¥1,940**, at +146 g robot mass. [FTECH-BUILD][CN-BACKUP][STS]
3. ~~Carrier alternative~~ **superseded (2026-09-27):** the robot now uses the owned dev-kit reference carrier at ¥0; the Waveshare IO-BASE-B (¥554, 100×79 mm, 93 g) and the A603 (¥1,400) are no longer purchase candidates. [CARRIER]

### All-Feetech selection & torque re-check (binding at 1.15 kg: hip_roll @2× = 0.91 N·m, hip_pitch/knee ≥0.59 N·m, wings/neck <0.15 N·m)

| Model | Role | Mass | Stall | Voltage | Protocol | ¥ Sep 2026 | hip_roll / knee / wings |
|---|---|---|---|---|---|---|---|
| ST-3215-**C018** (30 kg·cm @12 V) | legs ×6 | 55 g | **2.94 N·m @12 V**; ≈2.72 @11.1 V [LIN]; ≈1.47 @6 V [LIN] | **4.0–14 V** (OV >14 V) | FT-SCS TTL, ID0–253, 38400–1 Mbps | **¥118.50 现货 (1688)**; ¥109–129 [EST] | **PASS 3.0×** / PASS / overkill |
| SC-0043-C001 (coreless) | wings/neck ×4 | **6.6 g** | 2.2 kg·cm @6 V = **0.216 N·m** | 3.7–6 V | FT-SCS TTL, **38400–500 kbps** | ¥45–70 [EST] | — / — / **PASS 1.4×** |
| ST-3032 (middle try) | legs? | 20 g | 0.44 @6 V | ~5–7 V [EST] | FT-SCS TTL | ¥40–60 [EST] | FAIL (49%) / FAIL (75%) / PASS |
| STS3045M (middle try) | legs? | 34.8 g | 0.59 @6 V | 6 V | FT-SCS TTL | ¥60–90 [EST] | FAIL (66%) / MARGINAL / PASS |
| ST-3009 (brushless, middle try) | legs? | 45 g | 1.13 @7.4 V (0.88 @6 V) | 6–7.4 V | FT-SCS TTL | ¥100–150 [EST] | PASS only @7.4 V / PASS / heavy |
| HiWonder LX-16A | legs? | ~50 g [EST] | 1.67–1.96 @6–7.4 V | 6–7.4 V | FT-SCS-derived | ¥99–139 [EST] | PASS / PASS / heavy |

**Middle-weight finding (explicit):** no Feetech or other domestic serial-bus TTL servo in the **20–40 g class clears ≥1.0 N·m** as of Sep 2026. ST-3032 (20 g) fails knee; STS3045M (34.8 g) fails hip_roll; the lightest leg-capable servo is **ST-3009 at 45 g** — but it needs a **7.4 V rail** (extra buck from 3S), costs ≈ the C018, and saves only ~60 g over six legs → **dominated; the middle path is not recommended.** HiWonder LX-16A is torque-correct but 50 g-class and same price as C018 — no advantage. [FTECH-BUILD]

### Costed all-Feetech purchase list (domestic, Sep 2026)

| # | Part | Qty | Unit ¥ | ¥ | Mass (g) | Store link |
|---|---|---|---|---|---|---|
| 1 | Feetech ST-3215-C018 (legs) | 6 | 118.5 | 711 | 330 | [微雪·ST3215商品页](https://www.waveshare.com/product/st3215-servo.htm) · [淘宝搜索 ST3215 30kg 12V](https://s.taobao.com/search?q=ST3215%2030kg%2012V%20%E4%B8%B2%E8%A1%8C%E6%80%BB%E7%BA%BF%E8%88%B5%E6%9C%BA) |
| 2 | Feetech SC-0043-C001 (wings/neck) | 4 | 55 [EST] | 220 | 26 | [飞特·官方商品页](https://www.feetech.cn/en/559569) · [淘宝搜索 飞特 SC-0043](https://s.taobao.com/search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) |
| 3 | Spares: C018 ×1 + SC-0043 ×1 | 2 | — | 174 [EST] | 0 | 同上渠道 |
| 4 | Feetech 3-pin bus cables / extensions ~10 pc | 10 | 3 [EST] | 30 | — | [淘宝搜索 飞特 串行总线舵机线](https://s.taobao.com/search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) |
| 5 | 5 V BEC ≥3 A (wings/neck rail) | 1 | 20 [EST] | 20 | 15 [EST] | [淘宝搜索 5V 3A BEC 降压](https://s.taobao.com/search?q=5V%203A%20BEC%20%E5%8E%8B%E9%99%8D) |
| 6 | SN74LVC1G126 ×5 (bus transceiver) | 5 | 1 | 5 | ~0 | [立创商城搜索 SN74LVC1G126](https://www.szlcsc.com/search?q=SN74LVC1G126) |
| 7 | Feetech URT-1/URT-2 bench adapter | 1 | 45 | 45 | 0 (bench) | [淘宝搜索 飞特 URT-1](https://s.taobao.com/search?q=%E9%A3%9E%E7%89%B9%20URT-1%20%E8%B0%83%E8%AF%95%E6%9D%BF) |
| | **Servo+bus subtotal** | | | **≈ ¥1,205** | **356 (+146)** | |
| | **Full robot BOM (servo swap only; rest of §6 unchanged)** | | | **≈ ¥1,940** | **≈ 1,154 g ≈ 1.15 kg** | |

### Power & bus (one battery, one signal bus)

- One 3S pack feeds **both** the reference carrier (9–20 V barrel) and the servos. Legs (C018, 4–14 V) take **11.1 V direct**; wings/neck (SC-0043, max 6 V) take **5 V from the BEC** — one battery, no leg buck, only one small second rail.
- **One half-duplex TTL signal bus** for all 10 servos (same FT-SCS packet family). The 3-pin chains carry Vcc on pin 2, so power is fed by **taps**: leg segment fed at 3S, wing/neck segment fed at 5 V, SIG+GND continuous end-to-end → one Orin UART + one SN74LVC1G126 + one `feetech-servo-sdk`. If power-split signal integrity proves troublesome on the bench, the conservative fallback is **two buses** (2× UART + 2× transceiver, two power rails cleanly separated).
- Bus baud: run the mixed family at **115200–500 kbps** (SC-0043 caps at 500 k); 500 kbps preferred — a 10-servo sync cycle is ≈3–4 ms, well inside the 20 ms (50 Hz) budget. Re-flash C018 down from its 1 Mbps default. Voltage drop at 11.1 V is forgiving (0.5 V drop → 10.6 V, still in the 4–14 V window); keep chains ≤60 cm, 22 AWG, 2200 µF bulk cap.
- Cables: Feetech standard 3-pin bus cable (JST-family; usually included per servo; extensions ¥2–5 [EST]).

### Software (principle)

The **MuJoCo + PPO pipeline and the 50 Hz joint-target interface are unchanged** — only the low-level driver swaps Dynamixel Protocol-2.0 for the **Feetech SDK** (`sync_write` + `sync_read` exist in FT-SCS; servos reply in order on the broadcast). **Position + load readback confirmed** for the sim2real loop: ST3215 exposes Load / Position / Speed / Input Voltage / Current / Temperature; SC-0043 exposes pos / speed / load. Bench: FE-URT-2 / URT-1 (auto-direction, up to 1 Mbps). Quirks: factory default ID=1 on every unit (assign unique IDs one at a time first); 8-bit checksum, no byte-stuffing (parse by length field); brushless ST-3009 can throw CRC errors (not used in the recommended build). [FTECH-BUILD]

### Comparison — Dynamixel premium vs All-Feetech (Sep 2026, both all-domestic)

| Dimension | Dynamixel premium (6× XC330 + 4× XL330) | All-Feetech (6× C018 + 4× SC-0043) |
|---|---|---|
| Servo ¥ incl. spares | ¥6,790 | ≈ ¥1,205 (−82%) |
| **Total BOM ¥** | **≈ ¥7,523** | **≈ ¥1,940** |
| Servo mass | 210 g | 356 g (+146 g) |
| **Robot mass** | **≈ 1.01 kg** | **≈ 1.15 kg** |
| hip_roll @2× | req 0.79 N·m → XC330 1.10 N·m @6 V **PASS 1.39×** | req 0.91 N·m → C018 ≈2.72 N·m @11.1 V **PASS 3.0×** |
| Buses / protocol | 1 × Dynamixel P2.0 @1 Mbps | 1 × Feetech FT-SCS @500 kbps (power taps) |
| Rails | 1 × 6.0 V (UBEC) | legs 3S direct + 5 V BEC |
| Tooling | Dynamixel SDK / Wizard 2.0 (U2D2 optional) | Feetech SDK / URT-1 (already in §6) |
| Feedback for sim2real | pos / vel / current | pos / load (+V/current on C018) |
| Reliability | proven (microduck, OpenDuck Mini) | STS3215 proven in OpenDuck Mini; C018+SC-0043 mixed bus needs a bench enumeration check |

### Recommendation & decisions

**Recommendation:** if servo cost is the binding constraint, the **all-Feetech build (C018 legs + SC-0043 wings) is torque-safe (3.0× on the binding joint), single-bus, single-battery, ≈¥1,940 total** — the sensible cheap path; lower cost is its advantage, at +146 g mass and a smaller ecosystem. If mass and ecosystem matter more, **keep the Dynamixel build (≈¥7,523 / 1.01 kg / proven)**. The middle path (ST-3009) is not worth the extra rail complexity.

**Two decisions for the user:**
1. **Servo family:** Dynamixel premium (≈¥7,523 / 1.01 kg / proven ecosystem) **vs** all-Feetech (≈¥1,940 / 1.15 kg / one FT-SCS bus + Feetech SDK).
2. **If Feetech:** confirm the **one-bus power-tap** layout (legs 3S direct + wings 5 V BEC on one daisy chain) vs the safer **two-bus** split — bench-test mixed-family enumeration at 500 kbps before the full build. Note: SC-0043 live price/stock needs a 旺旺 confirm ([EST]).

---

## 8. Optional / deferred line items (priced, low effort)

| Item | ¥ | Notes |
|---|---|---|
| 5-DOF leg upgrade (hip_yaw + ankle ×2, 4× XC330) | ≈ 3,200 | mirrors microduck exactly; retrain policy with new kinematics |
| Head roll (+1 XL330) | ≈ 238 | crest/tilt expression |
| Beak servo (XL330) | ≈ 238 | microduck drives it daemon-side, outside RL |
| IMX219 8 MP MIPI camera | 35–60 | **reference-carrier CSI (15-pin)** — needs adapter for Pi-style IMX219 |
| 8×8 ToF (e.g. VL53L8CX) | 150–250 [EST] | deferred |
| Speaker/mic + TTS | 50–150 [EST] | deferred |
| Bluetooth gamepad (ShanWan Q34P) | 61 | teleop |
| Tail servo | ≈ 238 | deferred |

---
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

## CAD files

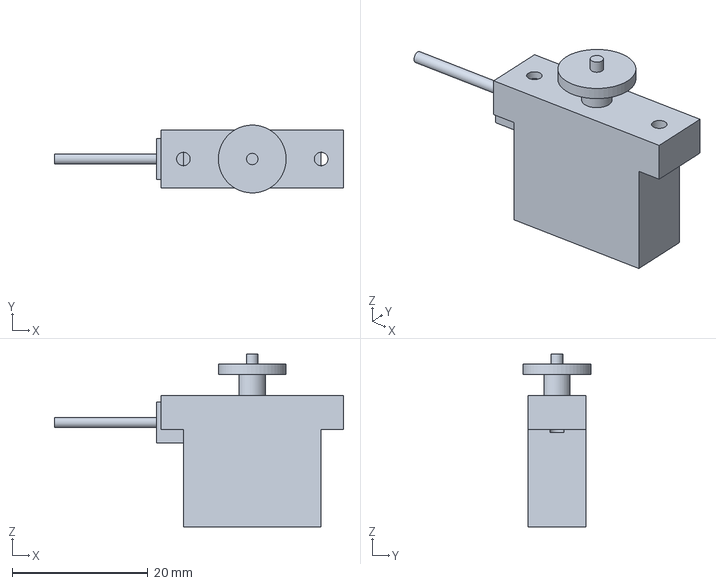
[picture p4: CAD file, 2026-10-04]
CAD/exports/step/sc0043_c001.STEP
42.6 x 10.00 x 25.5 mm

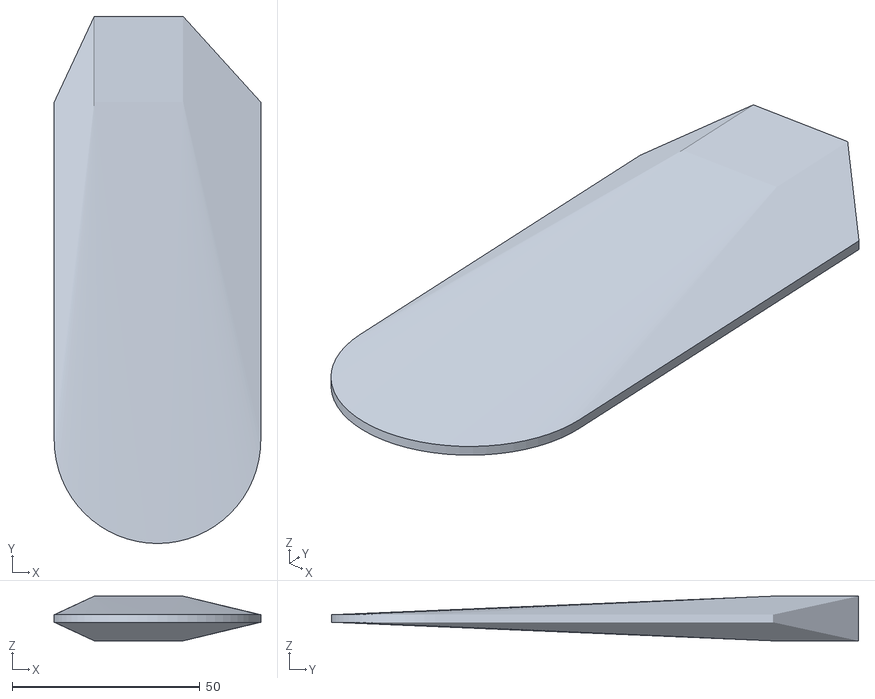
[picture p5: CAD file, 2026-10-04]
robot_description/meshes/collision/wing_R_col.stl
55.0 x 140.3 x 11.9

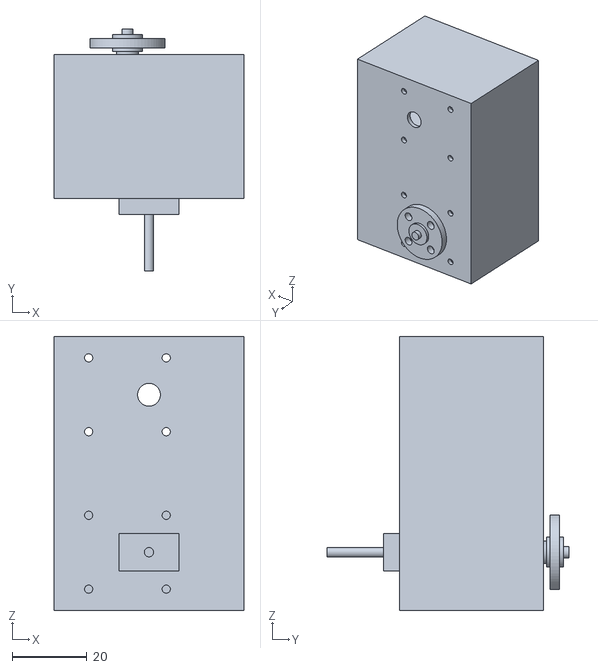
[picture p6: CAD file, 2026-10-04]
robot_description/meshes/visual/thigh_L.stl
50.6 x 64.5 x 73.1

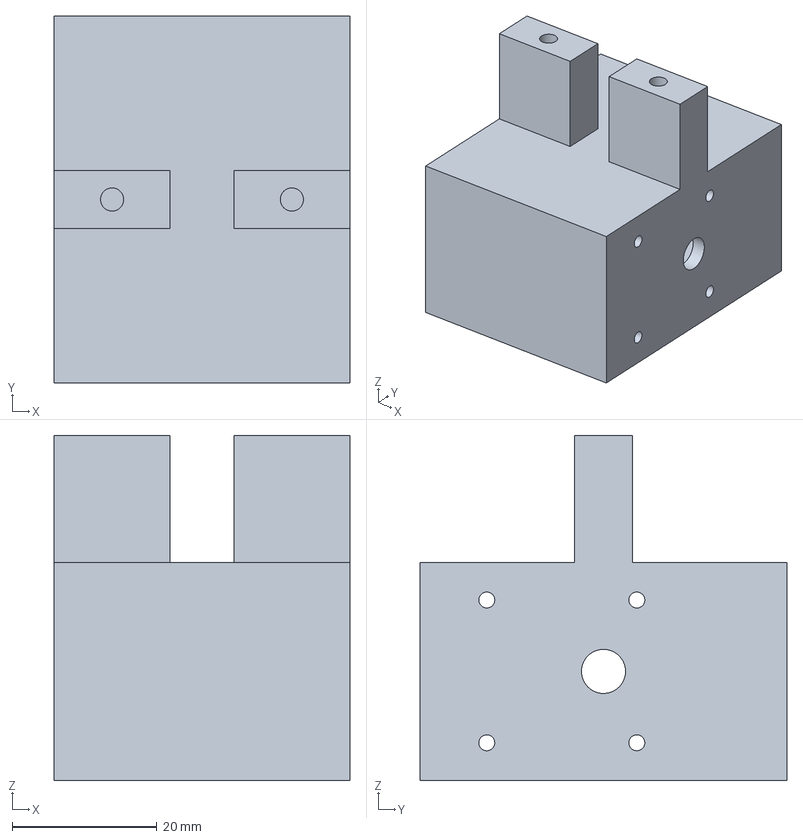
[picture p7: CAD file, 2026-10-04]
CAD/exports/step/hip_mount.STEP
40.8 x 50.6 x 47.6 mm

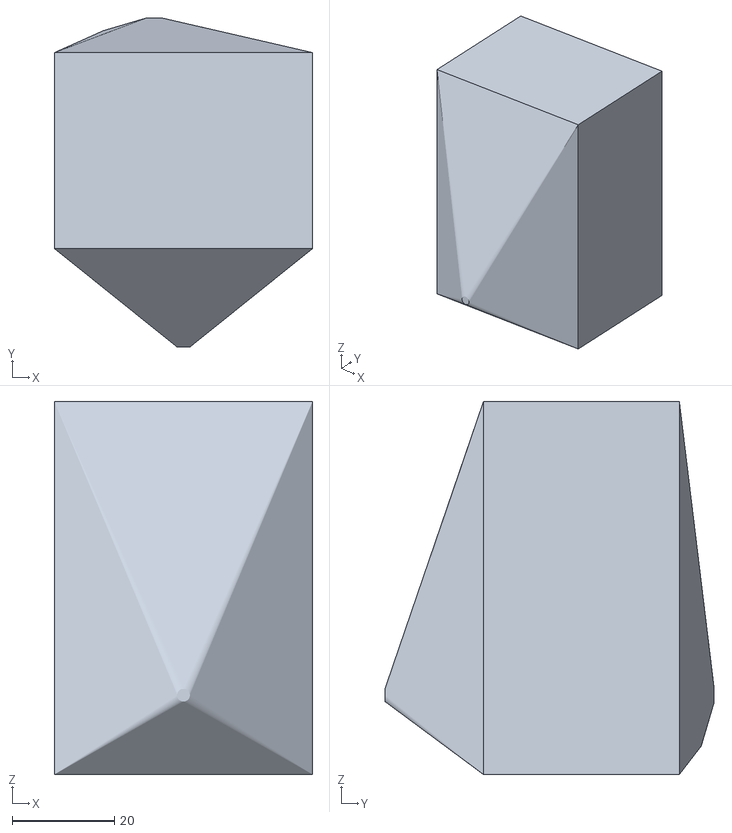
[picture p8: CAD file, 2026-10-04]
robot_description/meshes/collision/thigh_L_col.stl
50.6 x 64.5 x 73.1

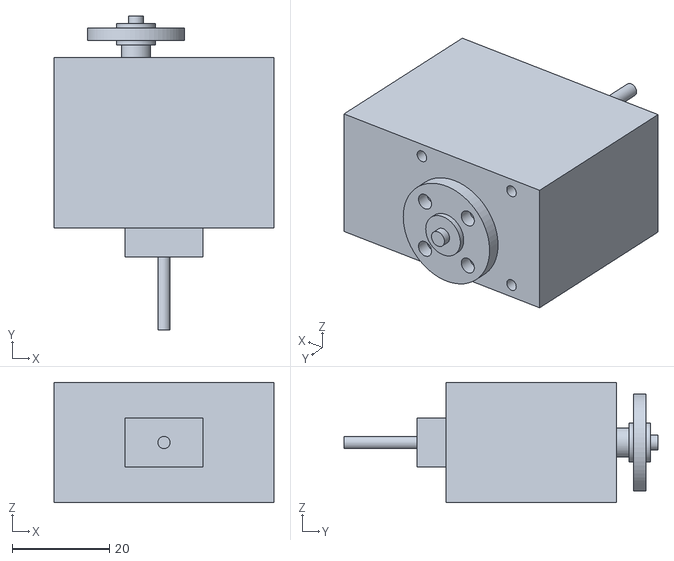
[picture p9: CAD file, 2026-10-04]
robot_description/meshes/visual/hip_L.stl
45.2 x 64.5 x 24.7

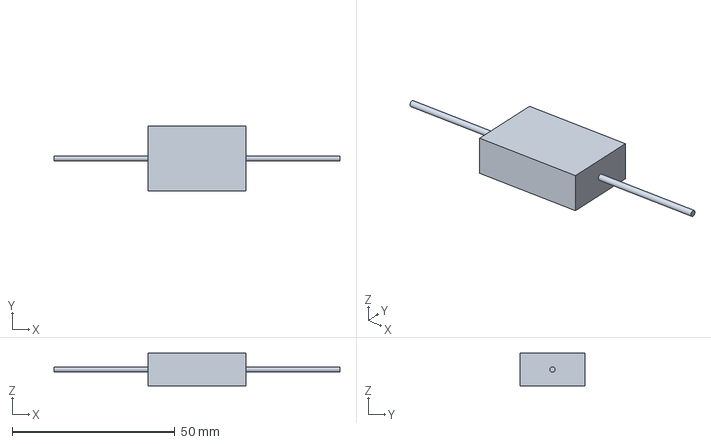
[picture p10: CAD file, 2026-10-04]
CAD/exports/step/bec_5v3a.STEP
88.0 x 20.0 x 10.0 mm

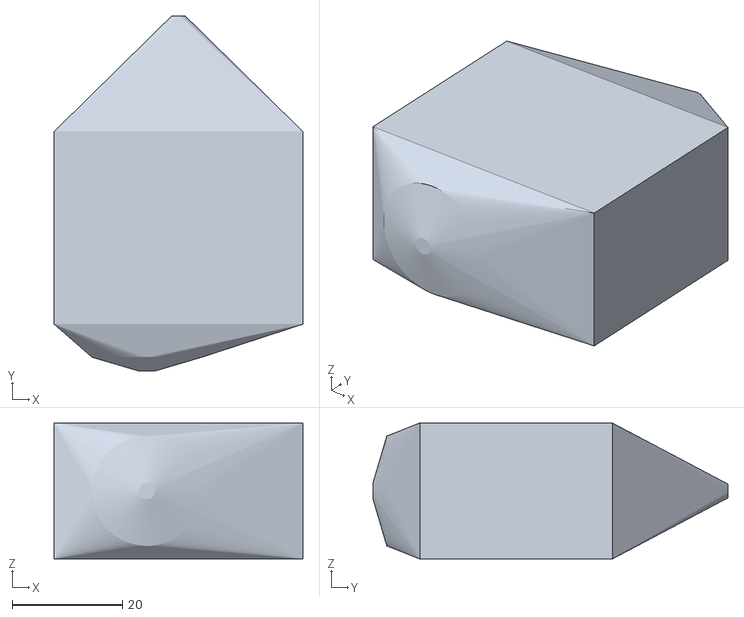
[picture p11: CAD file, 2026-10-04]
robot_description/meshes/collision/hip_R_col.stl
45.2 x 64.5 x 24.7

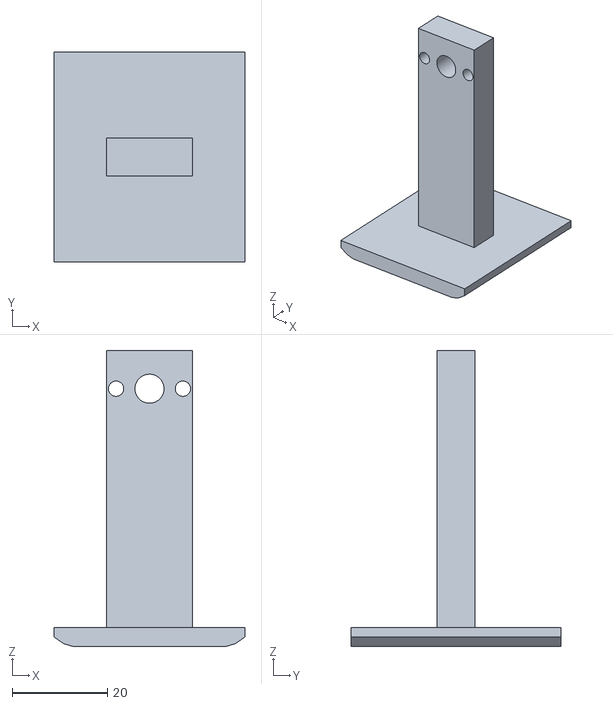
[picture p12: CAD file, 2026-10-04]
robot_description/meshes/visual/shin_L.stl
40.0 x 44.0 x 62.0

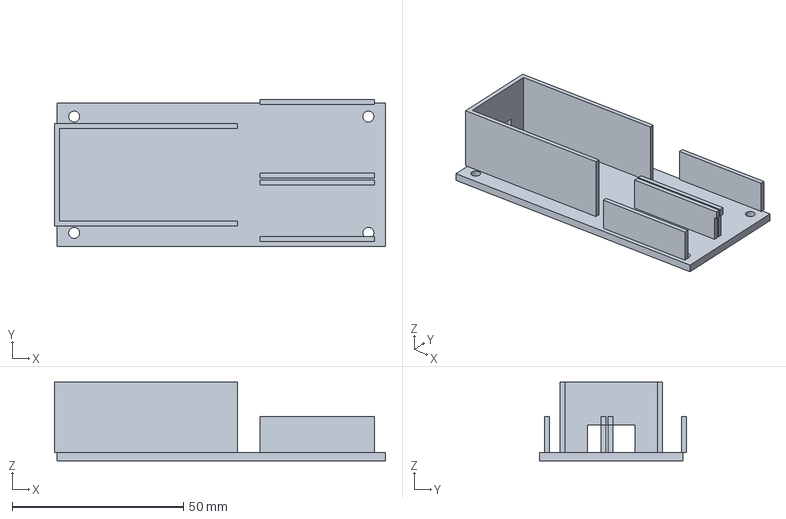
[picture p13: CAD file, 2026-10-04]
CAD/exports/step/power_mount.STEP
96.8 x 43.0 x 23.0 mm

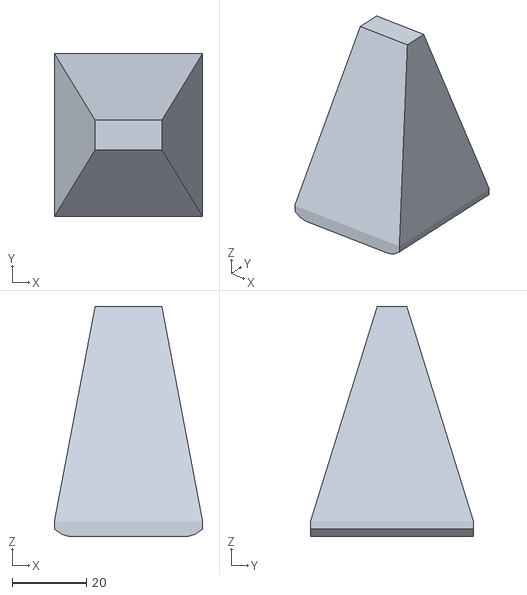
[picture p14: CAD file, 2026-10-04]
robot_description/meshes/collision/shin_R_col.stl
40.0 x 44.0 x 62.0

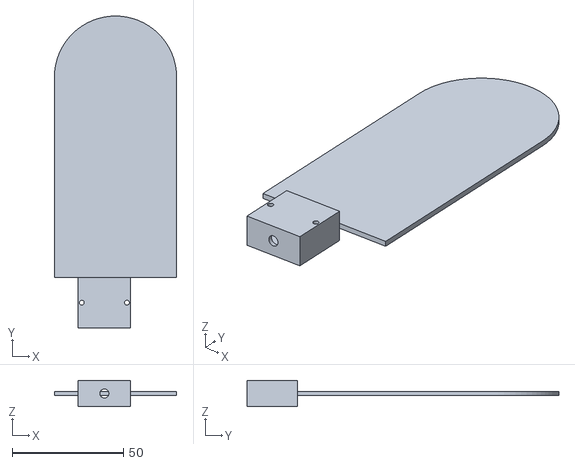
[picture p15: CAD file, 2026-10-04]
robot_description/meshes/visual/wing_L.stl
55.0 x 140.3 x 11.9

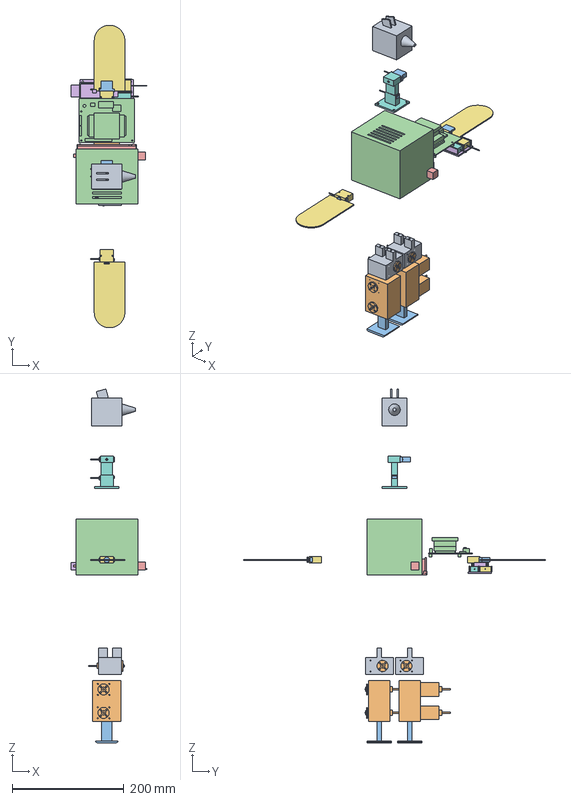
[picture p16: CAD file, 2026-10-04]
CAD/exports/step/LaFengParrot_Exploded.STEP
136.0 x 541.8 x 634.1 mm

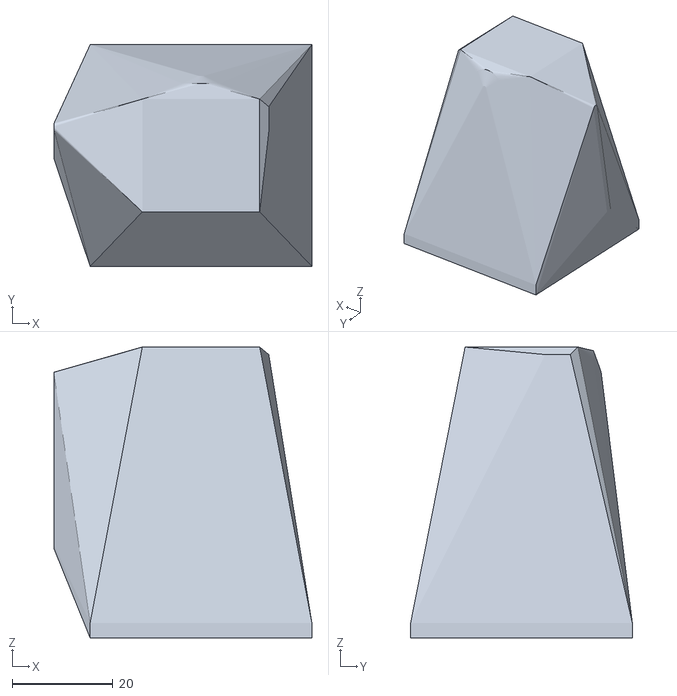
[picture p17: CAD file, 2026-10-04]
robot_description/meshes/collision/neck_yaw_col.stl
51.1 x 44.0 x 57.8

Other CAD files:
CAD/exports/step/shin_link.STEP
robot_description/meshes/collision/hip_L_col.stl
robot_description/meshes/visual/hip_R.stl
robot_description/meshes/visual/trunk.stl
CAD/exports/step/LaFengParrot_Standing.STEP
CAD/exports/step/battery_tray.STEP
CAD/exports/step/bearing_mr63.STEP
CAD/exports/step/fuse_holder.STEP
CAD/exports/step/head_shell.STEP
CAD/exports/step/imuc_icm42688p.STEP
CAD/exports/step/lipo_3s_2200.STEP
CAD/exports/step/neck_linkage.STEP
CAD/exports/step/orin_carrier.STEP
CAD/exports/step/st3215_c018.STEP
CAD/exports/step/thigh_link.STEP
CAD/exports/step/trunk_shell.STEP
CAD/exports/step/wing_arm_L.STEP
CAD/exports/step/wing_arm_R.STEP
CAD/exports/step/xt60_switch.STEP
CAD/exports/stl/battery_tray.STL
CAD/exports/stl/bearing_mr63.stl
CAD/exports/stl/bec_5v3a.STL
CAD/exports/stl/fuse_holder.STL
CAD/exports/stl/head_shell.STL
CAD/exports/stl/hip_mount.STL
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

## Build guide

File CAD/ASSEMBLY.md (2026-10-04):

# LaFengParrot — ASSEMBLY.md (part tree ↔ BOM, dimensions, fasteners, cables, joints)

Frozen build variant: **all-Feetech** (pinned, BOM §7). Legs 6× ST-3215-C018
(12 V, 30 kg·cm), wings/neck 4× SC-0043-C001, one FT-SCS TTL bus, one 3S pack.
Global frame: **+X beak/forward, +Y parrot-left, +Z up**; origin on the sagittal
plane at the two hip_roll output axes (the "hip plane", z=0). Units mm, masses g.

Placement authority: `source/assembly/ASSEMBLY_REPORT.md` §2 (**REV-B stability
rebuild**, 2026-09-27; repository path `CAD/`). Dimensions authority:
`dims/dimensions.md` (+ `dimensions.json`). Kinematic contract: `CONVENTIONS.md` §6.
Nothing here is invented; every number traces to one of those three files or a
BOM.md row. REV-B anchors: 54 mm hip rail, 40×44 feet (10 mm inner gap), neck
pitch axis z=185, carrier board-top z=72, total height 394 mm.

---

## 1. Part tree ↔ BOM mapping (1:1)

19 registry part_ids (the purchased fasteners/bearings are parameterized solids,
not printed). Frame prints → BOM §2 #9 mass line + §6 #16 PETG filament; hardware
solids → their §2/§6/§7 rows. "mounted qty" is the count baked into the standing
assembly (`poses._INSTANCES`, 29 instances over 19 part types).

| part_id (registry) | name | mounted qty | material | mass_g (CAD META) | BOM mass line | BOM purchase line |
|---|---|---|---|---|---|---|
| **Servos (FT-SCS bus)** |||||||
| `st3215_c018` | ST-3215-C018 leg servo (25T) | 6 | Al gearbox / case | 55 ea (330) | §2 #3-equivalent → §7 variant table (legs) | **§7 costed #1** (6×, ¥118.50, 1688 spot) |
| `sc0043_c001` | SC-0043-C001 wing/neck servo (28T) | 4 | plastic/metal gear | 6.6 ea (26.4) | §2 #4-equivalent → §7 variant | **§7 costed #2** (4×, ¥55 [EST]) |
| — spares (C018×1 + SC-0043×1, not mounted) | | 2 | | 0 mounted | — | **§7 costed #3** (174 [EST]) |
| **Compute / electronics** |||||||
| `orin_carrier` | Orin Nano Super dev-kit reference carrier + stock cooler + feet | 1 | PCB / Al heatsink / fan | 175 (assembly; §2 splits 15 g module #1 + 160 g board #2) | **§2 #1 + #2** | **§6 #1** (owned, ¥0; JD 10149183026930) |
| `lipo_3s_2200` | 3S 11.1 V 2200 mAh LiPo (XT60) | 1 | LiPo pouch | 185 | **§2 #7** (185 g, listing) | **§6 #11** (×2 incl. spare) |
| `bec_5v3a` | 5 V/3 A BEC (wings/neck rail) | 1 | PCB buck | 15 [EST] | §2 #6-equivalent (small 5 V buck) | **§7 costed #5** (¥20 [EST], 15 g) |
| `xt60_switch` | XT60 in-line power switch (M+F) | 1 | plastic/Cu | 30 | **§2 #8** (switch+fuse set, 30 g) | **§6 #13** (XT60 switch + 10 A fuse + holder) |
| `fuse_holder` | 5×20 mm glass fuse + in-line holder | 1 | glass/plastic | 10 | **§2 #8** (same set) | **§6 #13** (same set) |
| `imuc_icm42688p` | ICM-42688-P IMU breakout (20×20) | 1 | PCB/LGA | 4 [EST] | **§2 #11** (4 g) | **§6 #14** |
| **Frame prints (PETG FDM)** |||||||
| `trunk_shell` | Trunk shell (split upper/lower) | 1 | PETG | 230 ⚠ | **§2 #9** (PETG frame 230 g [EST] roll-up) | **§6 #16** (PETG 1 kg) |
| `hip_mount` | Hip-roll servo mount (L/R) | 2 | PETG | 42 ea | **§2 #9** | §6 #16 |
| `thigh_link` | Thigh link (2× C018 pocket) | 2 | PETG | 55 ea | **§2 #9** | §6 #16 |
| `shin_link` | Shin link w/ integrated fixed rocker sole | 2 | PETG | ≈18.8 ea CAD (20.2 incl. lump) | **§2 #9** | §6 #16 |
| `wing_arm` | Wing arm + printed panel (L/R) | 2 | PETG | 14 ea | **§2 #9** | §6 #16 |
| `neck_linkage` | Neck yaw+pitch bracket (2× SC-0043) | 1 | PETG | 30 | **§2 #9** | §6 #16 |
| `head_shell` | Parrot head shell (hollow) | 1 | PETG | 40 | **§2 #9** | §6 #16 |
| `battery_tray` | LiPo cradle tray | 1 | PETG | 35 | **§2 #9** | §6 #16 |
| `power_mount` | BEC / XT60 / fuse bracket | 1 | PETG | 28 | **§2 #9** | §6 #16 |
| **Purchased hardware (parameterized solids)** |||||||
| `fastener_m2` (M2.5/M3 kit) | ISO 4762 SHCS — M2/M2.5/M3 | set | 304 SS | 0.3 ea | **§2 #10** (fasteners + horns + bearings 60 g) | **§6 #17** (M2/M2.5/M3 304 kit) |
| `bearing_mr63` | MR63ZZ (3×6×2.5) / MR84 (4×8×2) | ~25 | chrome steel | 0.7 ea | **§2 #10** | **§6 #18** (MR63/MR84 ~25 pc) |

**Board-level (not a printed part_id, but on the robot):** SN74LVC1G126 bus
transceiver ×5 → **§6 #8 / §7 costed #6**; Feetech 3-pin bus cables ~10 pc →
**§7 costed #4**; wiring/sleeving/2200 µF bulk cap → **§2 #12** (45 g) +
**§6 #20** sleeving. Bench-only (not mounted): Feetech URT-1 adapter →
**§6 #9 / §7 costed #7**; 格氏 B3 charger → §6 #12.

> ⚠ **Mass reconciliation flag (not invented):** the CAD per-part frame masses
> (trunk 230 + hip 84 + thigh 110 + shin 52 + wing 28 + neck 30 + head 40 +
> tray 35 + power 28 ≈ **637 g**) sum well above BOM §2 #9's 230 g, which was
> the original duck-class estimate. The 230 g on `trunk_shell.META` appears to
> be that whole-frame figure carried onto one part. Next mass roll-up should
> replace §2 #9 with the summed CAD masses; robot total then lands above the
> 1.15 kg Feetech target (re-run the §1 torque margin, which scales ∝ M).

> ⚠ **META `bom_line` strings are stale:** several modules carry e.g.
> `bom_line="§2 #12"`/`"#13"`/`"#17"` that reference an older per-part mass table
> (the current BOM §2 ends at row #12). This table is authoritative; treat the
> in-code strings as deprecated.

---

## 2. Dimension table (sources: dimensions.md + ASSEMBLY_REPORT.md)

| Dimension | Value | Source | Verified? |
|---|---|---|---|
| Standing envelope x | [−64.0, +72.0] mm | REPORT §1 | measured STEP (XT60 switch/lead hardware; no 150 mm cable extremes) |
| Standing envelope y | [−190.9, +190.9] mm | REPORT §1 | measured (wing panel rounded tips) |
| Standing envelope z | [−138.0, +256.1] mm | REPORT §1 | measured (sole floor −138 → crest +256) |
| **Total structural height** | **394 mm** | REPORT §1 | −138 → +256.1 |
| Hip half-spacing / rail | 27 mm / **54 mm** | REPORT §2 (CONVENTIONS §6 nominal 52) | L/R hip_roll axes at y=±27 |
| Thigh link (hip_pitch → knee) | 42 mm | CONVENTIONS §6 / poses | placement z 0→−42 |
| Shin link (knee → sole) | 50 mm | CONVENTIONS §6 / poses | placement z −84→−134 |
| Leg drop (hip plane → foot) | 138 mm | REPORT §1 | z 0 → −138 |
| Foot sole | **40 (X) × 44 (Y) mm** compound rocker, 32 mm flat centre, 10 mm inner gap | REPORT §3 | symmetric 4 mm faceted toe/heel zones; fixed to shin, no wheel; L sole y[5,49], R y[−49,−5] |
| Trunk floor underside | z = 33 mm | REPORT §2 | trunk_shell placed (0,0,+33) |
| Trunk roof | z = 133 mm | REPORT §2 | trunk height = 100 mm |
| Carrier board-top | z = 72 mm | REPORT §2/§4 | orin_carrier placed (0,0,+72) |
| Carrier cooler exhaust top | z = 100 mm | REPORT §4 | roof vent z 128.5–133.5; ~28 mm plenum |
| Carrier standoff height | **33 mm [EST]** | REPORT §8 | feet bottom z=65.4 above trunk floor 33; verify printed bosses |
| Neck linkage base | z = 133 mm | REPORT §2 | neck_linkage placed (0,0,+133) |
| Neck pitch axis | z = 185 mm | REPORT §2 | linkage local z=52; head_shell placed (0,0,+185) |
| Head crest | z = 256 mm | REPORT §1 | measured (tilted crest fins) |
| Wing shoulder / panel tip | y = ±62 / ±190.9 mm | REPORT §2/§1 | span ≈ 382 mm |
| Battery pack | (0, −23, +49), box z 36–62 | REPORT §2 | low, CoM; clears carrier feet 64 by 2 mm |
| Power bracket Y | y = +23 | REPORT §2 | power_mount placed (0,+23,+36) |
| ST-3215-C018 body box | 45.2 × 24.7 × 35.0 mm | dims §1 | ✅ datasheet |
| C018 shaft / horn screw | 25T, Ø5.9 / **M3×6** | dims §1 | ✅ datasheet §6-9/§6-13 |
| SC-0043 body box | 20.3 × 8.5 × 19.39 mm | dims §2 | ✅ product page |
| SC-0043 horn screw | **M1.7** (28T, Ø3.9) | dims §2 | ✅ drawing |
| Orin carrier envelope | 103 × 90.5 × 34.77 mm | dims §3 | ✅ SP-11324 Fig 4-2 |
| LiPo pack | 105 × 34.5 × 26 mm, 185 g | dims §4 | ✅ listing |
| Bearings | MR63ZZ 3×6×2.5; MR84 4×8×2 (open) | dims §8 | ✅ |
| Fastener head/thread | M2 (Ø3.8), M2.5 (Ø4.5), M3 (Ø5.5) | dims §9 | ✅ DIN 912 |

---

## 3. Fastener list (derived from dimensions.md hole patterns)

Counts are nominal from the hardware hole layouts; final counts are confirmed at
first assembly. Screw-boss mapping: printed PETG bosses self-tap M2 (bore
thread+0.1 per CONVENTIONS §5); carrier uses M2.5 standoffs.

| Joint / assembly | Fastener | Qty (nominal) | Source |
|---|---|---|---|
| Each C018 leg servo in its pocket (hip_mount, thigh_link) | M2 / PA2.0 self-tap (Ø2.2 hole) | 4 per servo × 6 = 24 | dims §1 (4 corner PA2.0) |
| Each C018 horn → link retention | **M3×6** | 1 per servo × 6 = 6 | dims §1 "M3X6机牙" |
| C018 horn arm-to-link bracket | M3 (Ø3.2 clearance) | ~4 per horn × 6 = 24 | dims §1 "4-M3 / Ø3.2" |
| Each SC-0043 ear mount (wing shoulder, neck) | M2 (Ø2.0 ear hole) | 2 per servo × 4 = 8 | dims §2 |
| Each SC-0043 horn retention | **M1.7** | 1 per servo × 4 = 4 | dims §2 "28T-M1.7" |
| Orin carrier → trunk standoffs | M2.5×8 (4 corners) | 4 | dims §3 (M2.5, 4 plated holes) |
| IMU breakout → head pocket | M2 (4 corners) | 4 | dims §7 (4×M2 corners) |
| Joint pivot bearings | MR63ZZ (hip roll bore d=3) / MR84 (pitch/knee bore d=4) | ~25 total | dims §8, §6 #18 |
| Trunk upper/lower shell bolt-up, tray/power bracket bosses | M2 self-tap | per print_note | CONVENTIONS §5 |

---

## 4. Cable routing

**Power (one 3S pack, two rails):**
```
3S 11.1 V 2200 mAh (XT60, y=−23, low CoM)
 └─ 10 A in-line fuse (fuse_holder) → XT60 switch (xt60_switch, y=+23)
     ├─→ reference carrier barrel (9–20 V): Orin rail (board-top z=72)
     ├─→ LEG servos C018 ×6: 3S DIRECT (4.0–14 V rated; no leg buck)
     └─→ 5 V/3 A BEC (bec_5v3a) → WING/NECK servos SC-0043 ×4 (3.7–6 V max)
```
Legs take 11.1 V straight off the pack; only the small wings/neck segment goes
through the 5 V BEC (BOM §7 power section). Bulk cap 2200 µF low-ESR at the
first servo node; chains ≤60 cm, 22 AWG. Service ports per REPORT §4 (microSD
+Y, barrel +Y, USB +Y, 40-pin −Y, fan exhaust +Z, XT60 +X corner) are all open.

**Signal (one half-duplex FT-SCS TTL bus):**
```
carrier 40-pin header UART1 (pin8 TX / pin10 RX, 3.3 V)
  → SN74LVC1G126 tri-state buffer (free GPIO = bus direction: HIGH tx / LOW rx)
  → single 3-pin DATA chain: leg chain → wing/neck chain
```
- **Power taps on the same SIG+GND chain:** leg segment fed at 3S, wing/neck
  segment fed at 5 V (pin 2 Vcc breaks at the rail boundary); SIG+GND continuous
  end-to-end (BOM §7 "one bus, one SDK").
- **Baud 115200–500 kbps:** SC-0043 caps at 500 kbps; re-flash C018 down from
  its 1 Mbps default. 500 kbps preferred → 10-servo sync cycle ≈ 3–4 ms, inside
  the 20 ms / 50 Hz loop budget.
- Fallback if power-split signal integrity fails on the bench: two buses
  (2× UART + 2× transceiver, rails cleanly separated) — BOM §7 note.

---

## 5. Joint axes & zero poses (for the future MuJoCo model)

Zero pose = **standing** (trunk vertical, legs straight down z, wings level ±Y,
neck straight up). The crouched gait (hip_pitch 26°/knee ~0°) is a *policy*
offset, NOT the CAD zero — record both. All 10 joints, axis direction ∥ global
axis, position = output-axis origin in the global frame:

| # | joint | axis ∥ | position (x, y, z) mm | servo (instance) |
|---|---|---|---|---|
| 1 | hip_roll L | **X** | (0, +27, 0) | st3215_hiproll_L |
| 2 | hip_roll R | **X** | (0, −27, 0) | st3215_hiproll_R |
| 3 | hip_pitch L | **Y** | (0, +44.5, −42) | st3215_hippitch_L |
| 4 | hip_pitch R | **Y** | (0, −44.5, −42) | st3215_hippitch_R |
| 5 | knee_pitch L | **Y** | (0, +44.5, −84) | st3215_knee_L |
| 6 | knee_pitch R | **Y** | (0, −44.5, −84) | st3215_knee_R |
| 7 | wing_flap L | **Y** | (0, +71.7, +60) | sc0043_wing_L |
| 8 | wing_flap R | **Y** | (0, −71.7, +60) | sc0043_wing_R |
| 9 | neck_yaw | **Z** | (0, 0, +155.39) | sc0043_neckyaw |
| 10 | neck_pitch | **Y** | (0, +9.7, +185) | sc0043_neckpitch |

These REV-B positions are the **MuJoCo-inherited contract**: rebuild the MJCF at
these exact output-axis origins and zero angles; do not reuse REV-A z=203.

**Hip-rail deviation to carry into MuJoCo:** L/R hip_roll axes are **54 mm
apart (±27 mm)**, widened from the CONVENTIONS §6 nominal 52 mm and far wider
than microduck's **34 mm (±17 mm)** — the C018 body (45.2×24.7×35, 55 g) makes
the hip_mount housing 50.6 mm wide in Y, which overlaps across the sagittal
plane at ±17. MuJoCo kinematics MUST use 54 mm.

**Torque re-check reference (REPORT §6, REV-B):** lever r = 33 mm, required
@2× safety = 0.647·M. At the real built mass **M = 1.485 kg** (frame+hardware
1.38 kg + 105 g lump): required = **0.961 N·m** vs C018 stall ≈ 2.72 N·m @11.1 V
→ **margin 2.83× (PASS)**. Without lump (M = 1.38 kg): required 0.893 N·m →
3.05×. (REV-A's 3.65× was the lighter 1.15 kg estimate; the REV-B baked-centroid
mass supersedes it.)

---

## 6. Print & assembly notes

- **Material PETG FDM** (BOM §6 #16 PolyLite/金质). Structural walls ≥2.0 mm,
  servo pockets ≥1.6 mm, shell 1.6 mm (CONVENTIONS §5). Corner radii ≥1 mm.
- `trunk_shell`: split horizontally at local Z=50 into upper (roof + vent slots)
  and lower — bed-size split **finalized when the user's printer bed is known**
  (CONVENTIONS §5 / BOM §9: Ender-3 220 mm vs Bambu 256 mm).
- `hip_mount`: print with output axis (X) horizontal; ±X bearing bore faces away
  from supports for dimensional cleanliness.
- `thigh_link`: print on edge (beam vertical) so the two Y-axis bores are clean.
- `shin_link`: print on one 40×62 mm side so the rocker profile lies in the bed plane; 4 perimeters, 35% gyroid PETG, knee bore horizontal, no support.
- `wing_arm`: panel flat on bed (thin Z), shoulder pocket on edge.
- `neck_linkage`: base flat, yoke on edge; 2 mm walls; yaw bore clean.
- `head_shell`: print upside-down (skull crown on bed) so beak/crest need no supports.
- **Tray seating (REV-B):** `battery_tray` base underside now sits on the trunk
  floor (z=33); pack box z 36–62 clears the carrier feet (bottom z≈65.4) by 2 mm.
  The prior REV-A tray-vs-feet nick is resolved (REPORT §8) — no further trim needed.
- Designed contacts are expected (servos in pockets, horn/pivot mates, tray/pack,
  power devices in channels); REV-B keeps only 15 mm cosmetic cable stubs and
  BEC/fuse fly-leads that may lightly touch (benign, REPORT §3) — dress/sleeve them.

---

## 7. [EST] register & next-revision items

**[EST] values consumed by the frame (from dimensions.md register):**
1. C018 mount-hole xy coords — pixel-measured off Fig.9 (verify against physical servo).
2. C018 shaft protrusion ~6.0 mm.
3. SC-0043 mount-hole spacing 20.3 mm / ear Ø~2.
4. SC-0043 horn arm span ~15 mm.
5. SC-0043 connector JST family ("3-pin" only).
6. Orin carrier mount-hole xy + all connector xy (pixel-estimated off SP-11324).
7. Orin carrier feet/standoff height (~5 mm stock feet; the on-robot **33 mm**
   trunk standoffs are a printed-boss estimate, REPORT §8).
8. Orin carrier mount screw M2.5 (standard standoff).
9. BEC 5V3A board 30×20×10 mm / 100 mm leads / 15 g.
10. XT60 housing / switch body / fuse-holder body sizes (generic).
11. ICM-42688-P breakout PCB 20×20 / 4×M2 corners (only the bare IC is datasheet-verified).

**Next-revision backlog:**
- **Carrier standoff height 33 mm [EST]** — verify against printed trunk bosses;
  REV-B value = feet bottom z=65.4 above trunk floor z=33 (REPORT §8).
- **Power-device lead routing** — BEC/fuse/XT60 fly-leads may lightly touch
  channels (REPORT §3 cosmetic); route/sleeve at final assembly.
- **Frame mass roll-up** — the REV-B baked-centroid mass (1.38 kg frame+hardware,
  1.485 kg with lump) supersedes both the BOM §2 #9 (230 g) and the old per-part
  META sum; reconcile the BOM row against it. Hip_roll margin is now **2.83× @1.485 kg** (PASS).
- **Split decisions** — trunk shell (and any part >220 mm) splits pending the
  user's confirmed printer bed size.
- **Bench check before full build** — mixed C018+SC-0043 FT-SCS enumeration at
  500 kbps on the URT-1; if the one-bus power-tap layout misbehaves, fall back
  to two buses (BOM §7).

---

## 8. REV-A → REV-B before/after stability table

| Metric | REV-A (pre) | REV-B (post) |
|---|---|---|
| Overall height | 412 mm | **394 mm** |
| Sole width (Y) | 20 mm | **44 mm** |
| Sole length (X) | 30 mm | **40 mm** |
| Neck pitch axis z | 203 mm | **185 mm** |
| Carrier board-top z | 101 mm | **72 mm** |
| Whole-robot CoM height above floor | not computed | **162.5 mm** (target ≤180, PASS) |
| Lateral tipping angle | — | **16.8°** (half-base 49 mm) |
| Forward tipping angle | — | **7.0°** (half-base 20 mm; **binding direction**) |
| hip_roll verdict | PASS 3.65× @1.15 kg (estimate) | **PASS 2.83× @1.485 kg real** (2.72 N·m / 0.961 N·m) |

Sources: NVIDIA carrier spec SP-11324; Feetech ST-3215-C018 datasheet;
`dims/dimensions.md`; `ASSEMBLY_REPORT.md` §5 (CoM/statics) and §6 (torque).
Mass = 1.38 kg frame+hardware (real PETG volume ×1.27 + datasheet hardware),
1.485 kg with the +105 g fastener/horn/bearing/wiring lump at the assembly CoM.

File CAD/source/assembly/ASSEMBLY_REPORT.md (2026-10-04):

# LaFengParrot Assembly Report — REV-B stability rebuild

Date: 2026-09-27. Project directory `CAD/` (renamed from LaFengPirate).
Rewritten `source/assembly/poses.py` for the REV-B stability
anchors: 54 mm hip rail (±27), 40x44x4 feet with 10 mm inner gap, neck pitch axis
lowered to global z=185, carrier at board-top z=72, battery tray on the
trunk floor. All numbers below were computed from the baked solids (bbox,
volume, centroid via OCP), not estimated.

## 1. Envelope & total height

Reloaded `exports\step\LaFengParrot_Standing.STEP` (29 solids, valid):

| axis | min | max | note |
|---|---|---|---|
| X | −64.0 | +72.0 | +72 lipo/XT60 stub; −64 = XT60-switch lead (hardware). The old 150 mm cosmetic cable extremes are GONE. |
| Y | −190.9 | +190.9 | wing panel rounded tips (shoulder y=±62 + ~129 mm span). |
| Z | −138.0 | +256.1 | −138 = foot sole floor; +256 = head crest. |

Total height = 256.1 − (−138.0) = **394 mm**. Floor z=−138, hip plane z=0,
trunk roof z=133, neck pitch axis z=185, crest z≈256.

## 2. Placement table (standing, global frame: +X beak, +Y left, +Z up)

Rotation codes: ID = identity;
HIPL = `[[0,0,1],[1,0,0],[0,1,0]]` (shaft local Z→+X, body tail→+Y outboard);
HIPR = `[[0,0,1],[-1,0,0],[0,-1,0]]` (R mirror, tail→−Y outboard);
PIT = `[[1,0,0],[0,0,1],[0,1,0]]` (shaft local Z→+Y);
PITM = `[[1,0,0],[0,0,-1],[0,1,0]]` (R mirror, shaft→−Y outboard).

| instance | part_id | R | translation (x,y,z) | purpose |
|---|---|---|---|---|
| hip_mount_L | hip_mount(L) | ID | (0, +27, 0) | hip_roll housing, on hip plane |
| hip_mount_R | hip_mount(R) | ID | (0, −27, 0) | |
| thigh_link_L | thigh_link(L) | ID | (0, +27, −42) | hip_pitch pivot 42 below hip plane |
| thigh_link_R | thigh_link(R) | ID | (0, −27, −42) | |
| shin_link_L | shin_link(L) | ID | (0, +27, −84) | knee pivot; sole underside −54 → floor −138 |
| shin_link_R | shin_link(R) | ID | (0, −27, −84) | |
| trunk_shell | trunk_shell | ID | (0, 0, +33) | floor underside 33, roof top 133 |
| battery_tray | battery_tray | ID | (0, −23, +33) | base underside on trunk floor |
| power_mount | power_mount | ID | (0, +23, +36) | on cavity floor top (36) |
| wing_arm_L | wing_arm(L) | ID | (0, +62, +60) | shoulder |
| wing_arm_R | wing_arm(R) | ID | (0, −62, +60) | |
| neck_linkage | neck_linkage | ID | (0, 0, +133) | base on trunk roof; pitch axis local 52 → 185 |
| head_shell | head_shell | ID | (0, 0, +185) | on pitch horn |
| st3215_hiproll_L | st3215_c018 | HIPL | (23.25, +21.25, 0) | shaft on hip bore; body in pocket |
| st3215_hiproll_R | st3215_c018 | HIPR | (23.25, −21.25, 0) | |
| st3215_hippitch_L | st3215_c018 | PIT | (−5.75, +44.5, −42) | in top thigh pocket |
| st3215_hippitch_R | st3215_c018 | PITM | (−5.75, −44.5, −42) | mirrored, shaft outboard |
| st3215_knee_L | st3215_c018 | PIT | (−5.75, +44.5, −84) | in bottom thigh pocket |
| st3215_knee_R | st3215_c018 | PITM | (−5.75, −44.5, −84) | |
| sc0043_wing_L | sc0043_c001 | PIT | (0, +71.70, +60) | wing shoulder pocket |
| sc0043_wing_R | sc0043_c001 | PITM | (0, −71.70, +60) | |
| sc0043_neckyaw | sc0043_c001 | ID | (0, 0, +155.39) | shaft on yaw bore (linkage local 22.39) |
| sc0043_neckpitch | sc0043_c001 | PIT | (0, +9.70, +185) | pitch pocket at global 185 |
| orin_carrier | orin_carrier | ID | (0, 0, +72) | board-top 72 (feet bottom 65.4, cooler top 100) |
| lipo_3s_2200 | lipo_3s_2200 | ID | (0, −23, +49) | pack centre; pack box z 36..62 |
| xt60_switch | xt60_switch | ID | (−22, +23, +48.5) | in power_mount switch channel |
| bec_5v3a | bec_5v3a | ID | (+28, +32.5, +43.5) | BEC channel |
| fuse_holder | fuse_holder | ID | (+28, +13.5, +43.5) | fuse channel |
| imuc_icm42688p | imuc_icm42688p | ID | (−12, 0, +191.5) | head underside pocket |

## 3. Clash results (BRepAlgoAPI_Common, bbox pre-filter; threshold >0.01 mm3)

Only DESIGNED / COSMETIC contacts remain in every pose. No unintended CLASH.

| pose | unintended CLASH | notes |
|---|---|---|
| standing | **0** | 10.0 mm sole inner gap measured (L sole y[5,49], R y[−49,−5]); feet never touch. |
| (a) both feet flat | 0 | 10 mm inner gap confirmed; no foot-foot contact. |
| (b) left foot lifted 50 mm (+30 fwd, sole z=−88) | 0 design clashes | lifted foot bbox x[10,50] y[5,49] z[−88,−26]; clear of right foot (y≤−5). One residual 294 mm3 overlap of shin_L with the hip_pitch pocket is an ARTIFACT of modelling the lift as a rigid translation (real knee flexion keeps the shin top seated); foot-foot / foot-shin clearance itself is clear. |
| (c) left leg hip_roll +20 deg | 0 | abducted foot centre y=+72.1 (foot y[49,95]); clear of right foot and below the trunk (z≤−70 vs trunk z≥33). [Note: +20 deg about the hip axis physically lands the foot at y≈72; the ~47 mm value is the lateral excursion.] |
| (d) head pitched +45 deg nose-down | 0 design clashes | head zmin=169 → **36 mm above trunk roof 133** (≥3 required). Small head/pitch-servo overlap is the designed horn-pivot envelope. |
| (e) head yaw ±90 deg | 0 | no contact at either extreme. |

Designed contacts (expected): servo-in-pocket (all 10 servos), knee/hip pivots,
neck-on-roof, head-on-horn, IMU-in-head-pocket, lipo-in-tray, devices-in-channels,
carrier-on-standoffs, bolted bodies on the trunk floor. Cosmetic 15 mm cable
stubs and BEC/fuse leads may lightly touch (noted, benign).

## 4. Service access

- microSD / barrel / USB: carrier board-top at z=72, board edges z≈65.4–72;
  connectors at global y≈+20–29, all inside the +Y service window
  (trunk wall opening z 54–116, y 43–55, x ±40) → reach-through clear.
- 40-pin GPIO: on the −Y board edge (global y≈−34.5), open to the −Y interior.
- XT60 switch: at (−22,+23,48.5) beside the +Y window; battery XT60 exits the
  open +X end of the tray.
- Fan exhaust: cooler grille top z≈100; roof vent slots at z 128.5–133.5 aligned
  with the fan (board (50,30)→global (0,−9.5)). Clear **~28 mm plenum**
  (100→128.5); nothing blocks the flow path above the cooler.

## 5. CoM & statics (baked centroids, computed)

Frame mass = real volume (cm3) × 1.27 (PETG); hardware = datasheet masses.
Convention: **+105 g lump** (fasteners, horns, bearings, wiring) added at the
assembly CoM so it does not bias the balance.

- Total M (frame + hardware, before lump) = **1379.6 g ≈ 1.38 kg**.
- Total M with 105 g lump = **1484.6 g ≈ 1.485 kg**.
- CoM global = (**+0.8, −3.9, +24.5**) — near sagittal centre (battery at y=−23
  balanced by power devices at y=+23).
- **CoM height above floor z=−138 = 162.5 mm** (target ≤180 → PASS).
- CoM height above hip plane z=0 = 24.5 mm.

Tipping angles = atan(half-base / CoM_z above floor, CoM_z=162.5):

| direction | half-base | angle |
|---|---|---|
| lateral (sideways) | 49 mm | **16.8°** |
| forward | 20 mm | **7.0°** |

**Binding direction = FORWARD** (smaller angle). The short 20 mm forward
half-base is the weak axis; the 162 mm CoM height already meets the REV-B target.

## 6. hip_roll torque re-check

- Required @2× safety = 0.647 · M, r = 33 mm.
- At M = 1.485 kg (with lump): required = **0.961 N·m**.
- ST-3215-C018 stall ≈ 2.72 N·m @11.1 V → **margin 2.83×**.
- At M = 1.38 kg (without lump): required 0.893 N·m → **margin 3.05×**.
- PASS (≈3× as expected).

## 7. Exports (repository-relative paths)

Full assemblies:
- `CAD/exports/step/LaFengParrot_Standing.STEP`
- `CAD/exports/step/LaFengParrot_Exploded.STEP`

Per-part local STEP + STL (unrotated local frame), in
`CAD/exports/step/` and `CAD/exports/stl/`:
battery_tray, bearing_mr63, bec_5v3a, fuse_holder, head_shell, hip_mount,
imuc_icm42688p, lipo_3s_2200, neck_linkage, orin_carrier, power_mount,
sc0043_c001, shin_link, st3215_c018, thigh_link, trunk_shell, wing_arm_L,
wing_arm_R, xt60_switch.

## 8. Open / [EST] items

- Standoff height now 33 mm [EST] (carrier feet 65.4 above trunk floor). The
  previous tray-top nick (tray z≈64.5 vs feet 63.4) is RESOLVED: feet now sit
  0.9 mm above the tray top, and 3.4 mm above the battery pack top (62).
- Crest height 256 vs ~251 estimate is from the actual tilted crest fins.
- R-side thigh/knee servos use a mirrored PITM rotation (shaft outboard); the
  REV-A file had them on the wrong side — corrected here.
- No dimension was fabricated; EST items above are flagged.

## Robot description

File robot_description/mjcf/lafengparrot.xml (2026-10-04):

<mujoco model="lafengparrot">
  <compiler angle="degree" coordinate="local" eulerseq="xyz" meshdir="../meshes/visual"/>
  <option timestep="0.002" gravity="0 0 -9.81"/>

  <default class="main">
    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
    <joint damping="0.5" frictionloss="0.05"/>
  </default>

  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

  <worldbody>
    <light pos="0 0 3" dir="0 0 -1" diffuse="0.8 0.8 0.8" specular="0.1 0.1 0.1"/>
    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
    <body name="trunk" pos="0 0 0">
      <freejoint/>
      <inertial pos="0.001038 -0.006302 0.054028" mass="0.924834" fullinertia="0.00181601 0.00186349 0.00141591 -1.1491e-05 6.6285e-05 6.0741e-05"/>
      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
      <body name="hip_L" pos="0 0.027 0">
        <joint name="hip_roll_L" type="hinge" axis="1 0 0" limited="true" range="-22 22" armature="0.01"/>
        <inertial pos="-0.000108 -9.9e-05 -0.042" mass="0.059188" fullinertia="9.254e-06 1.1712e-05 1.5581e-05 1.39e-07 0 0"/>
        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
        <body name="thigh_L" pos="0 0 -0.042">
          <joint name="hip_pitch_L" type="hinge" axis="0 1 0" limited="true" range="-90 90" armature="0.01"/>
          <inertial pos="-4e-05 -4.1e-05 -0.029741" mass="0.142197" fullinertia="6.4095e-05 7.5887e-05 4.7524e-05 1.39e-07 -7.9e-08 -6.6e-08"/>
          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
          <body name="shin_L" pos="0 0 -0.042">
            <joint name="knee_L" type="hinge" axis="0 1 0" limited="true" range="0 150" armature="0.01"/>
            <inertial pos="0 0 -0.035691" mass="0.020159" fullinertia="8.396e-06 8.3e-06 2.781e-06 -0 -0 -0"/>
            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
          </body>
        </body>
      </body>
      <body name="hip_R" pos="0 -0.027 0">
        <joint name="hip_roll_R" type="hinge" axis="1 0 0" limited="true" range="-22 22" armature="0.01"/>
        <inertial pos="-0.000108 9.9e-05 -0.042" mass="0.059188" fullinertia="9.254e-06 1.1712e-05 1.5581e-05 -1.39e-07 0 -0"/>
        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
        <body name="thigh_R" pos="0 0 -0.042">
          <joint name="hip_pitch_R" type="hinge" axis="0 1 0" limited="true" range="-90 90" armature="0.01"/>
          <inertial pos="-4e-05 4.1e-05 -0.029741" mass="0.142197" fullinertia="6.4095e-05 7.5887e-05 4.7524e-05 -1.39e-07 -7.9e-08 6.6e-08"/>
          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
          <body name="shin_R" pos="0 0 -0.042">
            <joint name="knee_R" type="hinge" axis="0 1 0" limited="true" range="0 150" armature="0.01"/>
            <inertial pos="0 0 -0.035691" mass="0.020159" fullinertia="8.396e-06 8.3e-06 2.781e-06 -0 -0 -0"/>
            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
          </body>
        </body>
      </body>
      <body name="wing_L" pos="0 0.062 0.06">
        <joint name="wing_flap_L" type="hinge" axis="1 0 0" limited="true" range="-45 45" armature="0.002"/>
        <inertial pos="0.0041 0.055225 -0" mass="0.020454" fullinertia="2.9438e-05 4.088e-06 3.3386e-05 -9.45e-07 -0 -0"/>
        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
      </body>
      <body name="wing_R" pos="0 -0.062 0.06">
        <joint name="wing_flap_R" type="hinge" axis="-1 0 0" limited="true" range="-45 45" armature="0.002"/>
        <inertial pos="0.0041 -0.055225 0" mass="0.020454" fullinertia="2.9438e-05 4.088e-06 3.3386e-05 9.45e-07 0 -0"/>
        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
      </body>
      <body name="neck_yaw" pos="0 0 0.133">
        <joint name="neck_yaw" type="hinge" axis="0 0 1" limited="true" range="-90 90" armature="0.002"/>
        <inertial pos="-0.000157 0.000234 0.026486" mass="0.034111" fullinertia="1.5013e-05 1.5595e-05 3.982e-06 1.2e-08 4.2e-08 -1.89e-07"/>
        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
        <body name="head" pos="0 0 0.052">
          <joint name="neck_pitch" type="hinge" axis="0 1 0" limited="true" range="-45 45" armature="0.002"/>
          <inertial pos="0.003175 0 0.030144" mass="0.040903" fullinertia="2.0722e-05 3.0039e-05 2.5399e-05 -0 -1.108e-06 -0"/>
          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
        </body>
      </body>
    </body>
  </worldbody>

  <actuator>
    <position name="hip_roll_L" joint="hip_roll_L" kp="40" kv="4" ctrlrange="-0.383972 0.383972" forcelimited="true" forcerange="-2.72 2.72"/>
    <position name="hip_roll_R" joint="hip_roll_R" kp="40" kv="4" ctrlrange="-0.383972 0.383972" forcelimited="true" forcerange="-2.72 2.72"/>
    <position name="hip_pitch_L" joint="hip_pitch_L" kp="40" kv="4" ctrlrange="-1.5708 1.5708" forcelimited="true" forcerange="-2.72 2.72"/>
    <position name="hip_pitch_R" joint="hip_pitch_R" kp="40" kv="4" ctrlrange="-1.5708 1.5708" forcelimited="true" forcerange="-2.72 2.72"/>
    <position name="knee_L" joint="knee_L" kp="40" kv="4" ctrlrange="0 2.61799" forcelimited="true" forcerange="-2.72 2.72"/>
    <position name="knee_R" joint="knee_R" kp="40" kv="4" ctrlrange="0 2.61799" forcelimited="true" forcerange="-2.72 2.72"/>
    <position name="wing_flap_L" joint="wing_flap_L" kp="40" kv="4" ctrlrange="-0.785398 0.785398" forcelimited="true" forcerange="-0.22 0.22"/>
    <position name="wing_flap_R" joint="wing_flap_R" kp="40" kv="4" ctrlrange="-0.785398 0.785398" forcelimited="true" forcerange="-0.22 0.22"/>
    <position name="neck_yaw" joint="neck_yaw" kp="40" kv="4" ctrlrange="-1.5708 1.5708" forcelimited="true" forcerange="-0.22 0.22"/>
    <position name="neck_pitch" joint="neck_pitch" kp="40" kv="4" ctrlrange="-0.785398 0.785398" forcelimited="true" forcerange="-0.22 0.22"/>
  </actuator>
</mujoco>

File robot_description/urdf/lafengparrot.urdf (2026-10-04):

<?xml version="1.0"?>
<robot name="lafengparrot">

  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

  <link name="base_link">
    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
    <inertial>
      <origin xyz="0.001038 -0.006302 0.054028" rpy="0 0 0"/>
      <mass value="0.9248"/>
      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
    </inertial>
  </link>

  <link name="hip_L">
    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
    <inertial>
      <origin xyz="-0.000108 -9.9e-05 -0.042" rpy="0 0 0"/>
      <mass value="0.059186"/>
      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
    </inertial>
  </link>

  <link name="hip_R">
    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
    <inertial>
      <origin xyz="-0.000108 9.9e-05 -0.042" rpy="0 0 0"/>
      <mass value="0.059186"/>
      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
    </inertial>
  </link>

  <link name="thigh_L">
    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
    <inertial>
      <origin xyz="-4e-05 -4.1e-05 -0.029741" rpy="0 0 0"/>
      <mass value="0.142192"/>
      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
    </inertial>
  </link>

  <link name="thigh_R">
    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
    <inertial>
      <origin xyz="-4e-05 4.1e-05 -0.029741" rpy="0 0 0"/>
      <mass value="0.142192"/>
      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
    </inertial>
  </link>

  <link name="shin_L">
    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
    <inertial>
      <origin xyz="0 -0 -0.036022" rpy="0 0 0"/>
      <mass value="0.020543"/>
      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
    </inertial>
  </link>

  <link name="shin_R">
    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
    <inertial>
      <origin xyz="0 -0 -0.036022" rpy="0 0 0"/>
      <mass value="0.020543"/>
      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
    </inertial>
  </link>

  <link name="wing_L">
    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
    <inertial>
      <origin xyz="0.0041 0.055225 -0" rpy="0 0 0"/>
      <mass value="0.020453"/>
      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
    </inertial>
  </link>

  <link name="wing_R">
    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
    <inertial>
      <origin xyz="0.0041 -0.055225 0" rpy="0 0 0"/>
      <mass value="0.020453"/>
      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
    </inertial>
  </link>

  <link name="neck_yaw">
    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
    <inertial>
      <origin xyz="-0.000157 0.000234 0.026486" rpy="0 0 0"/>
      <mass value="0.03411"/>
      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
    </inertial>
  </link>

  <link name="head">
    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
    <inertial>
      <origin xyz="0.003175 0 0.030144" rpy="0 0 0"/>
      <mass value="0.040901"/>
      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
    </inertial>
  </link>

  <joint name="hip_roll_L" type="revolute">
    <parent link="base_link"/>
    <child link="hip_L"/>
    <origin xyz="0 0.027 0" rpy="0 0 0"/>
    <axis xyz="1 0 0"/>
    <limit lower="-0.3839724354" upper="0.3839724354" effort="2.72" velocity="5.235987756"/>
  </joint>

  <joint name="hip_roll_R" type="revolute">
    <parent link="base_link"/>
    <child link="hip_R"/>
    <origin xyz="0 -0.027 0" rpy="0 0 0"/>
    <axis xyz="1 0 0"/>
    <limit lower="-0.3839724354" upper="0.3839724354" effort="2.72" velocity="5.235987756"/>
  </joint>

  <joint name="hip_pitch_L" type="revolute">
    <parent link="hip_L"/>
    <child link="thigh_L"/>
    <origin xyz="0 0 -0.042" rpy="0 0 0"/>
    <axis xyz="0 1 0"/>
    <limit lower="-1.570796327" upper="1.570796327" effort="2.72" velocity="5.235987756"/>
  </joint>

  <joint name="hip_pitch_R" type="revolute">
    <parent link="hip_R"/>
    <child link="thigh_R"/>
    <origin xyz="0 0 -0.042" rpy="0 0 0"/>
    <axis xyz="0 1 0"/>
    <limit lower="-1.570796327" upper="1.570796327" effort="2.72" velocity="5.235987756"/>
  </joint>

  <joint name="knee_L" type="revolute">
    <parent link="thigh_L"/>
    <child link="shin_L"/>
    <origin xyz="0 0 -0.042" rpy="0 0 0"/>
    <axis xyz="0 1 0"/>
    <limit lower="0" upper="2.617993878" effort="2.72" velocity="5.235987756"/>
  </joint>

  <joint name="knee_R" type="revolute">
    <parent link="thigh_R"/>
    <child link="shin_R"/>
    <origin xyz="0 0 -0.042" rpy="0 0 0"/>
    <axis xyz="0 1 0"/>
    <limit lower="0" upper="2.617993878" effort="2.72" velocity="5.235987756"/>
  </joint>

  <joint name="wing_flap_L" type="revolute">
    <parent link="base_link"/>
    <child link="wing_L"/>
    <origin xyz="0 0.062 0.06" rpy="0 0 0"/>
    <axis xyz="0 1 0"/>
    <limit lower="-0.7853981634" upper="0.7853981634" effort="0.22" velocity="5.235987756"/>
  </joint>

  <joint name="wing_flap_R" type="revolute">
    <parent link="base_link"/>
    <child link="wing_R"/>
    <origin xyz="0 -0.062 0.06" rpy="0 0 0"/>
    <axis xyz="0 1 0"/>
    <limit lower="-0.7853981634" upper="0.7853981634" effort="0.22" velocity="5.235987756"/>
  </joint>

  <joint name="neck_yaw" type="revolute">
    <parent link="base_link"/>
    <child link="neck_yaw"/>
    <origin xyz="0 0 0.133" rpy="0 0 0"/>
    <axis xyz="0 0 1"/>
    <limit lower="-1.570796327" upper="1.570796327" effort="0.22" velocity="5.235987756"/>
  </joint>

  <joint name="neck_pitch" type="revolute">
    <parent link="neck_yaw"/>
    <child link="head"/>
    <origin xyz="0 0 0.052" rpy="0 0 0"/>
    <axis xyz="0 1 0"/>
    <limit lower="-0.7853981634" upper="0.7853981634" effort="0.22" velocity="5.235987756"/>
  </joint>

</robot>

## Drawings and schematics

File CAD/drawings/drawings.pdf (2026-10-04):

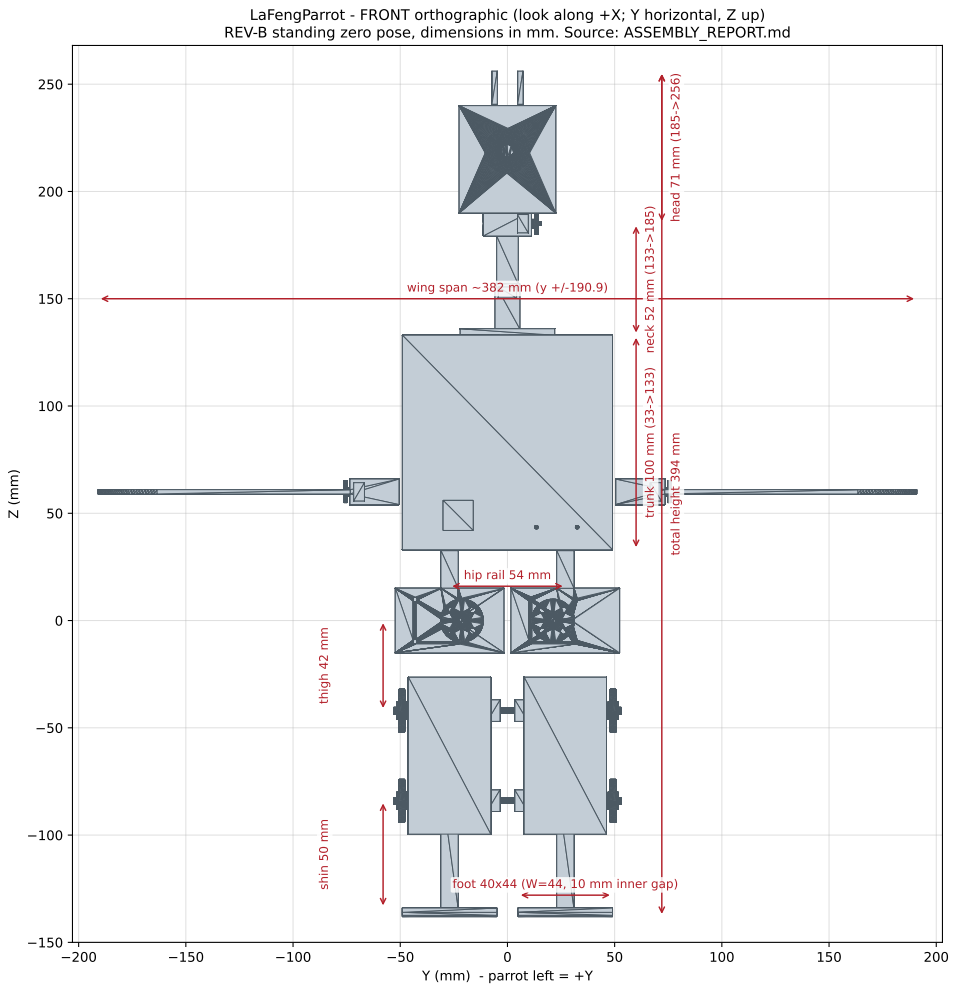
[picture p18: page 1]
hip rail; wing span ~382; head 71 mm (185->256); foot 40x44 (W=44, 10 mm; inner gap)

LaFengParrot - FRONT orthographic (look along +X; Y horizontal, Z up)
REV-B standing zero pose, dimensions in mm. Source: ASSEMBLY_REPORT.md

trunk 100 mm (33->133) neck 52 mm (133->185)

total height 394 mm

thigh 42 mm shin 50 mm

Y (mm) - parrot left = +Y

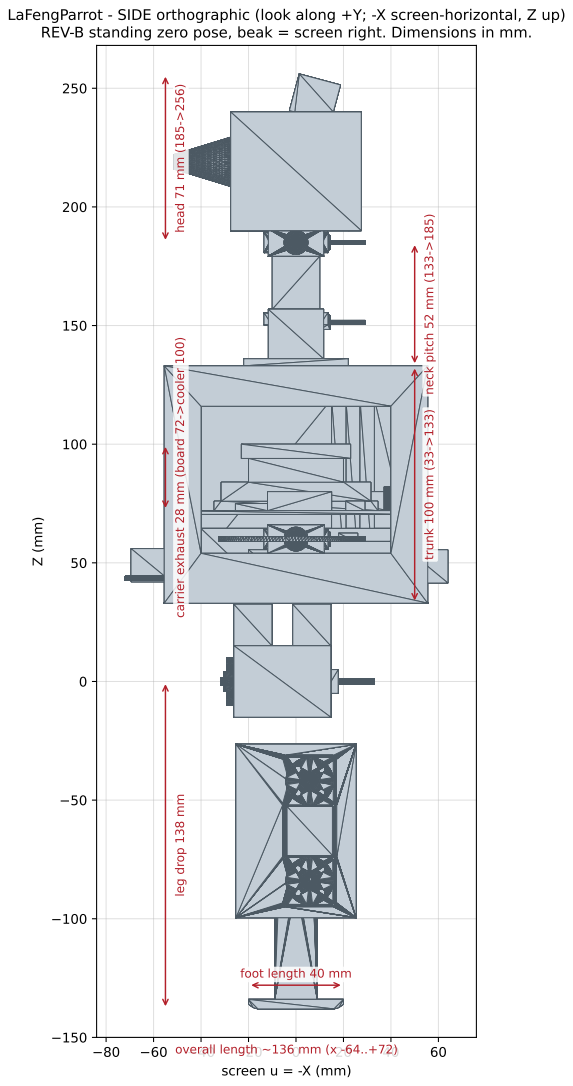
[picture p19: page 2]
screen u = -X (mm); REV-B standing zero pose, beak = screen right. Dimensions in mm. leg drop 138 mm; trunk 100 mm ⁽³³⁻>¹³³⁾ carrier exhaust 28 mm ⁽board 72⁻>cooler 100⁾; neck pitch 52 mm ⁽¹³³⁻>¹⁸⁵⁾ head 71 mm ⁽¹⁸⁵⁻>²⁵⁶⁾

LaFengParrot - SIDE orthographic (look along +Y; -X screen-horizontal, Z up)

foot length 40 mm

overall length ~136 mm (x -64..+72)

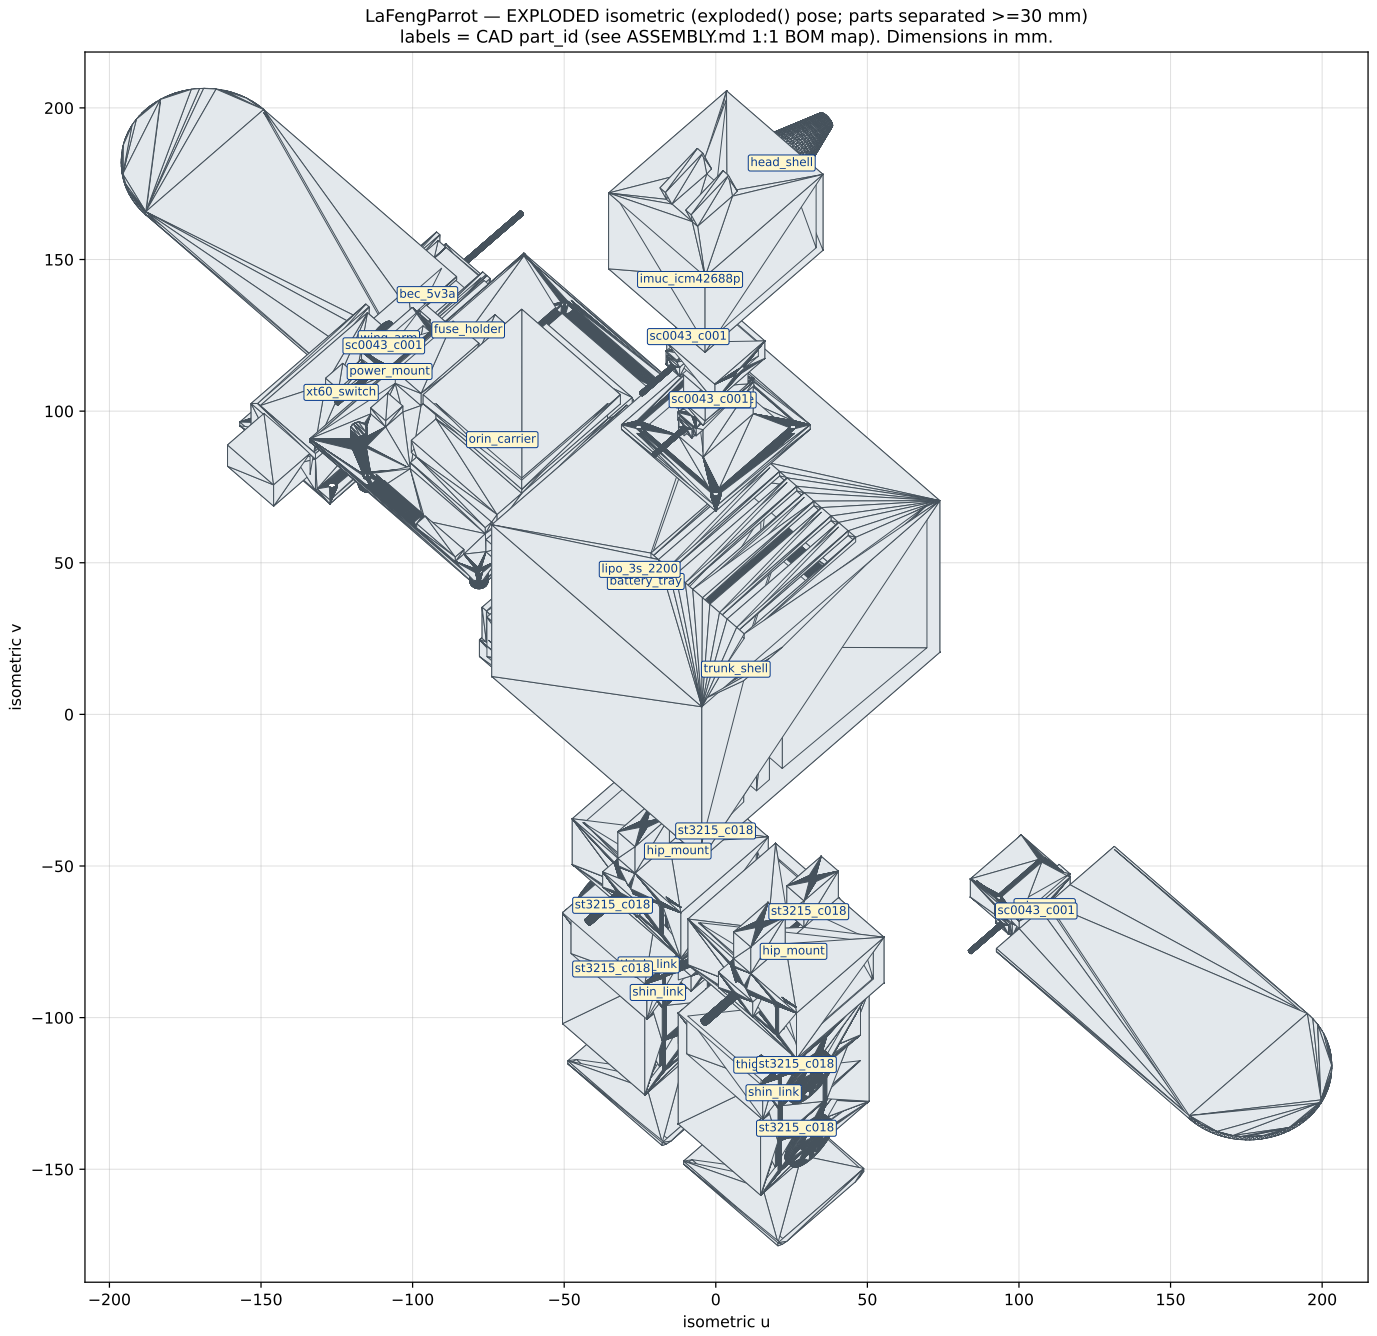
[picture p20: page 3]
isometric u; isometric v; hip_mount; thigh_link; shin_link; trunk_shell; battery_tray; power_mount; wing_arm; neck_linkage; head_shell; orin_carrier; lipo_3s_2200; xt60_switch; bec_5v3a; fuse_holder; imuc_icm42688p

LaFengParrot — EXPLODED isometric (exploded() pose; parts separated >=30 mm)
labels = CAD part_id (see ASSEMBLY.md 1:1 BOM map). Dimensions in mm.

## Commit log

2026-10-04 Add LaFengParrot CAD, simulation, and RL baseline
    [LaFengParrot_Exploded.STEP, LaFengParrot_Standing.STEP, battery_tray.STEP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]
2026-10-04 Update README with current status and details
